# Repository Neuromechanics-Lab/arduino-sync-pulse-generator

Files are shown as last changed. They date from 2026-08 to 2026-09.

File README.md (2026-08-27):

# Arduino Sync Pulse Generator

A pseudo-random square wave generator for ATmega32U4-based Arduino boards, designed for temporal synchronization of multi-device experimental recordings.

## Purpose

When recording from multiple devices simultaneously (e.g., Vicon motion capture, EEG, eye tracking), each device has its own clock. By feeding the same pseudo-random sync signal into all devices, you can use **cross-correlation** in post-processing to precisely align all recordings temporally.

The pseudo-random pattern produces a sharp autocorrelation peak, making it far more robust for temporal alignment than a regular periodic signal.

## Hardware

Both supported boards use the ATmega32U4 at 5V/16MHz and are fully compatible.

| Board | Output pins | FQBN |
|---|---|---|
| Arduino Leonardo | 20 (0–13, A0–A5) | `arduino:avr:leonardo` |
| Pro Micro ATmega32U4 5V (e.g. Teyleten Type-C) | 18 (0–10, 14–16, A0–A3) | `arduino:avr:micro` |

- **Output voltage**: 5V HIGH / 0V LOW (hardware fixed by ATmega32U4)
- **Connection**: Wire any output pin + GND to a BNC cable for each device

If your equipment expects 3.3V logic, use a voltage divider or level shifter on the output.

> **Pro Micro note**: The standard Pro Micro footprint does not break out pins 11, 12, or 13.
> Use pins 0–10, 14–16, and A0–A3 for signal output (18 pins total).

## Setup

### Install Arduino CLI (macOS)

```bash
brew install arduino-cli
arduino-cli core update-index
arduino-cli core install arduino:avr
```

### Compile

**Arduino Leonardo:**
```bash
arduino-cli compile --fqbn arduino:avr:leonardo sync_pulse_generator
```

**Pro Micro ATmega32U4 5V:**
```bash
arduino-cli compile --fqbn arduino:avr:micro \
  --build-property "compiler.cpp.extra_flags=-DBOARD_PRO_MICRO" \
  sync_pulse_generator
```

### Upload

Both boards use the same upload command pattern. Find your port first:

```bash
arduino-cli board list
```

**Arduino Leonardo** — requires a double-tap of the reset button to enter bootloader mode:

1. Double-tap the reset button
2. Immediately run:

```bash
arduino-cli upload --fqbn arduino:avr:leonardo -p /dev/cu.usbmodemXXXX sync_pulse_generator
```

**Pro Micro ATmega32U4** — also requires a double-tap of the reset button. The port may change after the reset tap, so watch `board list` output and use the bootloader port (often a different address than the running port):

```bash
arduino-cli upload --fqbn arduino:avr:micro -p /dev/cu.usbmodemXXXX sync_pulse_generator
```

Replace `/dev/cu.usbmodemXXXX` with the port shown by `arduino-cli board list`.

## Configuration

### Compile-time defaults

Edit `sync_pulse_generator/config.h` to change default timing ranges and PRNG seed. These are loaded on first boot or after an EEPROM reset.

To target the Pro Micro pin layout, either uncomment `#define BOARD_PRO_MICRO` at the top of `config.h`, or pass `-DBOARD_PRO_MICRO` as a build flag (shown in the compile commands above).

### Runtime commands

Connect via serial monitor at **115200 baud**:

| Command | Description |
|---|---|
| `high <min> <max>` | Set HIGH duration range in ms (default: 50-500) |
| `low <min> <max>` | Set LOW duration range in ms (default: 50-500) |
| `seed <value>` | Set PRNG seed and restart pattern (default: 42) |
| `save` | Persist current settings to EEPROM |
| `reset` | Revert to config.h defaults |
| `start` | Start signal output |
| `stop` | Stop signal output (pins LOW) |
| `restart` | Re-seed PRNG and restart with same seed |
| `config` | Show current configuration |
| `help` | Show available commands |

### Persistence

Settings changed via serial commands are **not** saved automatically. Use `save` to write them to EEPROM so they survive power cycles. Use `reset` to revert to compile-time defaults.

## Reproducibility

The generator uses a deterministic xorshift32 PRNG. The same seed always produces the same sequence, so you can verify alignment across sessions or regenerate the expected pattern in analysis software.

## Alignment Utilities

Post-processing tools to align multi-device recordings using the sync channel. Located in `sync_pulse_generator/utils/` — see **[`utils/README.md`](sync_pulse_generator/utils/README.md)** for full documentation, worked examples for two and for many signals, and the complete function reference.

### Three ways to align

| Method | Use when | Files |
|---|---|---|
| **Cross-correlation** | Both copies of the signal look alike | `sync_align.*` |
| **Edge timing** | One copy went through an EMG amplifier, or you want per-transition error bars | `edge_sync.*`, `detect_edges`, `edge_delay` |
| **Timecode frames** | You need absolute time, or to know which generator run a recording belongs to | `timecode.*`, `decode_timecode`, `align_to_timecode` |

An EMG amplifier's high-pass turns each step into a transient spike, so the two waveforms stop resembling each other and correlation degrades — but their transition *times* still line up exactly, which is what edge timing measures.

### Languages

All three implement the same functions with the same names and behaviour.

| Language | Location | Dependencies |
|---|---|---|
| Python | `utils/python/` | numpy (scipy only for EMG filtering) |
| MATLAB | `utils/matlab/` | base MATLAB (Signal Processing Toolbox optional) |
| R | `utils/R/` | base R + stats (`signal` only for EMG filtering) |

### Core functions

- **`load_c3d_analog`** — Dependency-free C3D reader (no BTK or ezc3d needed), plus Nexus CSV exports. Takes rate, labels, and scaling from the file.
- **`detect_edges`** — Square-wave transitions to sub-sample precision. Two detectors: a Schmitt trigger for directly recorded signals, and signed peak detection for EMG-passed ones. Reports onset rather than peak by default, avoiding a 1–2 ms bias.
- **`edge_delay`** — Delay between two edge trains, matched by polarity and causally. Returns median, spread, per-polarity agreement, drift, and plain-language quality warnings.
- **`sync_report`** — One call for every sync channel in a recording, with a full pairwise matrix.
- **`shift_timestamps`** — Apply a measured delay to any number of channels, by relabelling time (lossless) or resampling.
- **`process_emg`** — Standard EMG chain returning every intermediate stage, with flat/railed channel detection.
- **`decode_timecode` / `align_to_timecode`** — Absolute anchors and run identity; refuses to fit across a generator restart.
- **`find_sync_lag` / `align_recordings`** — Cross-correlation alignment (offset, merge, bundle modes).

### Python CLI

```bash
# Every sync channel in a file, measured against a reference
python edge_sync.py report SquareWaveTest01.c3d

# Two named channels
python edge_sync.py delay trial.c3d --ref SquareDirect --test SquareWirelessEmg

# List what a file contains
python edge_sync.py channels trial.c3d

# Write a copy with corrected timestamps
python edge_sync.py shift trial.c3d --delay 20.6 -o corrected.csv

# Cross-correlation (the older path)
python sync_align.py lag file1.csv file2.mat --sync-col sync --fs 1000
python sync_align.py generate --seed 42 --duration 60 --fs 1000 -o expected.csv
```

Recordings in separate files, from separate devices, at different sample rates all compare directly — edge times are in seconds, so no resampling is needed.

## Author

Nathan Baune — Emory University

## License

MIT License. See [LICENSE](LICENSE).

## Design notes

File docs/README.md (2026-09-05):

# PRE-Sync documentation

| Document | Contents | Source of truth |
|---|---|---|
| [DATASHEET.md](DATASHEET.md) | Specifications, ratings, failure behaviour | hand-written |
| [INTERFACE.md](INTERFACE.md) | Pinout, signal levels, serial commands | **generated** from firmware |
| [BOM.csv](BOM.csv) | Bill of materials | hand-maintained |
| [wiring/presync-schematic.svg](wiring/presync-schematic.svg) | Electrical schematic | **generated** from `presync-schematic.yml` |
| [wiring/presync-harness.png](wiring/presync-harness.png) | Panel harness diagram | **generated** from `presync-harness.yml` |
| [TEST_PROCEDURE.md](TEST_PROCEDURE.md) | Acceptance tests for a built unit | hand-written |
| [ACCESSORIES.md](ACCESSORIES.md) | Fan-out pod, LED converter | hand-written |
| [api/](api/) | Python analysis toolkit reference | **generated** from docstrings |

## Regenerating

Three documents are generated and must not be edited by hand — an edit is
lost the next time they are rebuilt, and the source is the authority:

```sh
python3 tools/gen_interface_doc.py           # docs/INTERFACE.md
.venv-docs/bin/python tools/gen_schematic.py # docs/wiring/presync-schematic.svg
tools/gen_wiring.sh                          # docs/wiring/presync-harness.*
tools/gen_api_docs.sh                        # docs/api/
```

The last three need a virtual environment and graphviz:

```sh
brew install graphviz
python3 -m venv .venv-docs
.venv-docs/bin/pip install wireviz pdoc pyyaml numpy scipy pyxdf matplotlib
```

## Checking the BOM

```sh
python3 tools/check_bom.py
```

Reports which lines still lack a manufacturer part number, supplier or price.
The BOM is incomplete until this runs clean; **do not fill it with estimates**,
since a fabricated price is worse than a visible blank.

## What is still missing

Measurements only a built unit can provide, tracked in
[TEST_PROCEDURE.md](TEST_PROCEDURE.md): rise/fall times, channel-to-channel
skew, generator clock accuracy in ppm, and demonstration of the independent
driver claim. These appear as *TBM* in the datasheet.

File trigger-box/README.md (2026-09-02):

# PRE-Sync — trigger box for sync_pulse_generator

3D-printed, copper-foil-lined enclosure for the Pro Micro (ATmega32U4 5V)
running [`../sync_pulse_generator`](../sync_pulse_generator). Eight BNC sync
outputs; TRIG input for chaining multiple boxes off one master signal.

**Three parts, no supports anywhere:** the **frame** (walls + corner posts,
open at both ends), the **face plate** (flat display plate, screws onto one
end with countersunk M3 self-tappers into the posts), and the **lid**
(screws onto the other end). Assembled ~174 × 51 × 37 mm, 3 mm walls.

**Faces:**
- **Front:** 8 BNC outputs at 19 mm pitch, numbered `1`–`8` left to right,
  `OUTPUTS` caption above. **Each jack is driven by its own Arduino pin**
  through a 220 Ω series resistor (all pins carry the identical signal), so
  every cable has a full 5 V driver behind it — no shared drivers, no pots.
  Level control per device, if needed, is an inline attenuator pod (idea
  logged, not built).
- **Rear:** `TRIG IN` BNC + SPDT mode toggle (`FREE RUN ⟷ TRIG RUN`, arrow
  from TRIG RUN to the IN jack) under a `CONTROL` caption.
- **Left end:** `PWR` barrel jack, centered.
- **Right end:** 10-32 thread-forming ground/tether screw, dead center —
  self-taps through the wall into the copper foil inside (the shield's single
  ground point), tether ring terminal under the head outside.
- **FACE PLATE (deployed top):** Neuromechanics Lab icon
  (`logo-icon-filled.svg` — outlines filled so every shape is a solid inset) + **PRE-Sync** wordmark as a 1.2 mm **inset whose floor
  is colored** — a 0.6 mm slab of filament 1 sits directly under the recess
  inside the body, so you look into the inset and see orange at the bottom,
  body color on the walls. **10 mm blue LED centered in the neuron's soma.**
- **Lid (deployed bottom):** 4 corner screws, two keyhole mounts (M4/#8
  heads; slots toward the front — hang and slide to lock), lab attribution
  inset inside.

**All lettering is inset** (0.8 mm deboss; walls in Futura Medium 4.6 mm with light stroke fattening
so the grooves print smooth).

## Top bracing and PCB mount

The bottom edge is closed by the lid and both ends by the face and lid screws,
but the top opening had nothing holding its long edges apart — 168 mm of
unsupported wall that could bow. Two things fix that:

- **A ledge** (`ledge_w` 2.5 mm × `ledge_h` 3 mm) runs the inside of the top
  rim, turning the free edge into a flange. A flange resists bending far better
  than the same mass added as wall thickness. It stops short of the corner posts
  so the face plate still seats on the posts.
- **Two cross beams** (`beam_w` 8 mm × `beam_h` 4 mm) span the short way, wall to
  wall, at the PCB post spacing. They close the load path between the long
  walls, so the walls can no longer splay. Their top faces are **flush with the
  rim**, coplanar with the ledge and the corner posts.

**Print the frame RIM DOWN.** Flush beams are what makes that work: the whole
top surface — rim, ledge and both beams — becomes the first layer, laid flat on
the plate, and the hanging posts grow vertically off solid material. Recessed
even slightly, the beams would be 45 mm unsupported bridges whichever way up the
part printed, and the post pilots that have to hold an M2.5 thread would be
forming off a bridged surface. No supports either way up, but rim-down is the
one that prints the posts accurately.

Because the beams share the rim plane with the corner posts, the face plate now
seats on them too — more bearing surface, but the beam tops must be exactly
coplanar or the plate rocks. The model is (verified: max z equals the rim
exactly, not a layer proud).

**The board hangs from the beams**, horizontal, on four posts dropping from
their undersides (`pcb_hang` 4 mm, M2.5 self-tappers into `pcb_pilot` 2.2 mm).
This replaces the earlier scheme, where four posts stood off the rear wall and
the board mounted vertically on their ends.

Two things that buys:

- **Serviceable from both faces.** Take the logo face off (top) to reach the
  beams and the component side; take the lid off (bottom) to reach the solder
  side.
- **Out of the way of everything.** The board is centred at `pcb_cx` 34 /
  `pcb_cy` −11, so it spans x −4..72 and y −21..−1 — pulled back against the
  rear wall, leaving 23.5 mm clear in front for the eight BNC bulkhead bodies,
  and well clear in x of the face LED at x −51. It lands at z 23, 6 mm above the
  z 17 centreline of the BNC and barrel jacks.

> **`pcb_dx` (76) and `pcb_dy` (15) are still unverified.** `dx` carried over
> from the vertical scheme; `dy` is a guess at the hole spacing across the
> board's 20 mm dimension. Measure the real board before printing — four posts
> at the wrong pitch line up with nothing. Check them on `trigger-hole_test`
> along with the connector diameters.

## Printing

STLs only — slice in Bambu Studio yourself (never a command-line slice; the
CLI can't resolve Bambu's filament profiles and produces 0 g / no-extrusion
files). `./export-parts.sh` regenerates `exports/stl/*.stl` after any change.
Every part prints flat exactly as exported — **no rotation, no supports.**

1. `trigger-hole_test` first (~10 min): every hole + keyhole + an inset label
   sample. VERIFY bnc/switch/barrel/led diameters against the real parts.
2. `trigger-frame` — walls only, either end down. Single color.
3. **Face plate, two-color:** import `trigger-face.stl` AND
   `trigger-face_art.stl` together → **Yes** to "load as a single object with
   multiple parts" → `trigger-face_art` (the recess-floor slab) → filament 1
   (orange), `trigger-face` → filament 2. Face up as exported. The color
   change is 3 layers just below the top surface. Check the sliced weight is
   a real number before printing.
4. `trigger-lid` flat as-is, single color.

Assembly: 4 × M3 self-tappers through the face plate's countersinks into the
posts (either in-plane rotation of the plate works — pick the one where the
wordmark reads the way you want relative to the OUTPUTS wall), 4 more
through the lid. LED holder nut goes on inside the plate before it's screwed
down.

## Copper foil shielding

Line the interior with conductive-adhesive copper tape: overlap seams,
ground the foil to circuit GND at exactly ONE point (the ground screw), keep
it clear of the Pro Micro's underside. BNC shells touching the foil is fine
(shield = GND).

## Electrical notes

- Outputs: 8 pins (Pro Micro: 4, 5, 6, 7, 8, 9, 10, 14) → 220 Ω → BNC
  center; all BNC shells to GND. Pins 2/3 are reserved by the firmware for
  TRIG IN / mode switch.
- SPDT toggle: MTS-102 style (6 mm bushing, 6.5 mm hole, fit-tested).
- TRIG IN → 1 kΩ series → pin 2; switch common → pin 3, FREE throw → GND.
  See the sync_pulse_generator README for the arming logic.

## Accessory pucks (`pods.scad`)

Round Ø60 pucks on a shared body, all parts flat, no supports. Each puck =
`base` (keyhole plate, common) + a ring + a top plate, 4 × M3 self-tappers
each end into the ring's posts. Hung by the keyhole, the top plate faces out
and the jacks run left–right. Exported as `exports/stl/pod-*.stl`.

| Puck | Ring | Top | Inside |
|---|---|---|---|
| **GAIN** (inline attenuator) | `pod-ring` — IN + OUT, 40 tall | `pod-top_gain` — pot, `GAIN`, arc arrow `LOW` → `HIGH` | IN center → pot end, wiper → OUT center, other end → shields. High-impedance loads only |
| **LED** | `pod-ring_in` — IN only, 28 tall | `pod-top_led` — Ø20 boss with a **1/4"-20 heat-set insert** for a hollow **gooseneck** (mic/lamp type: wires run inside, holds any position, never free-spins) | IN center → series resistor (~220 Ω for a 10 mm LED at 5 V) → up the gooseneck |
| | | `pod-led_head` — screws onto the gooseneck's far end: insert in the bottom, 10 mm LED press-fit + 14 mm ring seat on top, wires through the middle | |
| **SOUND** | `pod-ring_in` | `pod-top_sound` — pocket for a 23 mm **5 V active piezo buzzer**, grille, `VOL` pot, `LEVEL`/`EDGE` toggle | see below |

**SOUND puck circuit** — buzzer + ← VOL pot (series, volume) ← IN center.
The SPDT toggle sits on the buzzer's − side and picks how it reaches the
shield (ground):

- `LEVEL`: buzzer − → shield directly. Sounds for the whole HIGH.
- `EDGE`: buzzer − → NPN collector (2N3904 / BC547), emitter → shield. Base
  ← 22 kΩ ← 1 µF ← IN center, with 10 kΩ base→shield and a 1N4148 from
  shield to base (cathode at base) to clamp the falling-edge spike. The
  capacitor passes only the rising edge, so the transistor conducts for
  ≈ RC ≈ 20 ms: one blip per rising edge, powered by the line itself (every
  HIGH lasts ≥ 50 ms). Change 1 µF / 22 kΩ for a longer or shorter blip.

Parts to buy: 1/4"-20 heat-set brass inserts (two per LED puck — VERIFY the
OD against `gn_insert_d`), a 1/4"-20 gooseneck (6–12"), a 5 V active piezo
buzzer (VERIFY `buzzer_d`). Print `pod-top_led` boss-up and `pod-top_sound`
as exported (outside face on the bed, pocket walls growing up).

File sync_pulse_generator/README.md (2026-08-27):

# Sync Pulse Generator

Pseudo-random square-wave sync pulse generator on an ATmega32U4 (Pro Micro /
Leonardo), for cross-correlation-based temporal alignment of multi-device
recordings (Vicon, EEG, DAQ, audio, video). Hardware enclosure: the
**PRE-Sync** box (`../trigger-box/`) — 2 gain-controlled banks of 3 BNC
outputs, TRIG input + FREE/TRIG run switch.

All output pins carry the same 5 V / 0 V signal. HIGH and LOW durations are
drawn pseudo-randomly (xorshift32, fixed seed) from configurable ranges —
the same seed always produces the same sequence, so the expected waveform
can be recreated offline and any recording aligned to it by
cross-correlation (`utils/R/sync_align.R`).

## Timecode frames (hybrid mode, default ON)

Every 10 s (configurable) the pseudo-random train is interrupted by one
**timecode frame** encoding elapsed seconds since the PRNG started —
constant 5 V amplitude, information purely in pulse timing. **Frames start
exactly on the tick:** the random segment that would cross the tick is cut
short 20 ms early, the output holds LOW for that lead-in, and the first
preamble pulse rises ON the tick — so a decoded frame's first edge marks
precisely `elapsed` seconds of generator time (ms-accurate anchors, not
"somewhere in that second").

```
preamble                 payload: 52 bits as gaps between 5 ms pulses
P──10──P──10──P ── g₀ ──P── g₁ ──P── ... ──g₅₁──P
                  15 ms = 0   25 ms = 1
bits, MSB first:  [16-bit run ID][32-bit elapsed seconds][4-bit checksum]
checksum: XOR of all 4-bit nibbles of run ID and elapsed seconds
```

**Run ID** is a persistent EEPROM counter that increments on every PRNG
(re)start — power-up, `start`, `restart`, `seed`, `reset`. Since the fixed
seed makes every run's waveform identical, the run ID is what tells run 731's
`t=50 s` apart from run 732's: **(run ID, elapsed) uniquely identifies every
moment the box has ever emitted.** A recording found years later self-reports
which session it belongs to. (Counter wraps at 65535; it is stored outside
the config block, so `save`/`reset` never touch it.)

Why: with a fixed seed the PR train itself already encodes absolute position
(any chunk cross-correlates to one offset in the reconstructed template) —
frames add three practical things on top: **no-compute anchors** (decoding
one frame beats correlating against an hours-long template), **drift-immune
point anchors** (each frame decodes independently of accumulated sample-rate
error), and **run identity** (see Run ID above — the one thing the PR train
cannot provide, since every run's waveform is identical). Frames are deterministic and consume
no PRNG draws, so the complete hybrid signal is still exactly reproducible
from (seed, config): cross-correlation works across frames like any other
signal — they're simply part of the fingerprint (and each frame differs, so
no periodicity artifact).

Design rules baked in:
- PR durations (default min 50 ms) can never imitate frame timing
  (5–25 ms) — preambles are unambiguous. The cut-short segment before a
  frame can be arbitrarily brief, which is why the lead-in is 20 ms: a
  short HIGH stub then the lead-in gives a 25 ms edge interval — neither a
  preamble (15) nor a bit (20/30).
- The PRNG draw for the cut-short segment still happens, so the template
  generator reproduces the clamp exactly from (seed, config).
- **Edge-polarity friendly:** frame pulses have constant width, so a
  falling-edge-only recording decodes identically; its anchors are exactly
  `TC_PULSE_MS` (5 ms) late, corrected by `edge="falling"` in the decoders.
  In an unlabeled edge stream, the frame's 5 ms intervals even identify
  which edges are rises.
- Cameras/LED pods can't resolve frame gaps — they don't need to: they
  align by cross-correlation against the recreated template as always.

## FREE RUN / TRIG RUN (the rear-panel switch)

The PRE-Sync box's SPDT toggle selects the run mode (read live — flipping
it mid-session acts immediately):

- **FREE RUN** — output starts at power-up, exactly as before.
- **TRIG RUN** — outputs hold LOW until a rising edge arrives on the
  **TRIG IN** BNC, then a fresh run starts (new run ID, elapsed = 0).
  Chain several boxes from one master pulse and they start in sync; each
  box still stamps its own run ID. Once running, further TRIG edges are
  ignored — re-arm by flipping the switch or power-cycling.

Wiring (see `config.h`): switch common → pin 3, FREE-throw → GND;
TRIG BNC center → ~1 kΩ series resistor → pin 2. The TRIG input must sit
LOW ≥ 20 ms before an edge counts, so an unconnected jack can never
false-trigger (an idle master holding 0 V arms it). Pins 2 and 3 are
excluded from the output set; all other pins still carry the signal.

## Serial commands (115200 baud)

```
high <min> <max>   low <min> <max>    seed <value>
tc on|off          tcint <seconds>    save
start | stop | restart | reset | config | help
```

`tc on` / `tcint` take effect immediately, on the run's interval grid
(never a burst of overdue frames); `tcint` minimum is 2 s (a frame is
~1.65 s). `save` persists everything (including timecode settings) to
EEPROM.
EEPROM magic is 0xA8 — older saved configs (0xA7) are invalidated and
defaults reload on first boot after this firmware update.

## Concept figure

`docs/timecode_figure.{svg,png}` — the hybrid signal at three zoom levels
(12 s overview → one frame with its fields bracketed → preamble and first
bits at ms scale), generated bit-exact from the reference implementation by
`utils/python/timecode_figure.py`. `timecode_figure_bare.*` is the same
waveform with no labels, for annotating from scratch. SVG stays editable.

## Offline tools (`utils/`)

Full documentation, worked examples for two and for many signals, and the
function reference across all three languages: **[`utils/README.md`](utils/README.md)**.

Three ways to align, for different situations:

- **Edge timing** (`edge_sync.py`, `detect_edges`/`edge_delay` in all three
  languages) — measures the delay transition by transition, with error bars.
  The right tool when one copy of the square wave has been through an EMG
  amplifier: the high-pass turns each step into a spike, so the waveforms no
  longer resemble each other but their edge *times* still line up.
- **Timecode frames** (`timecode.py`, `decode_timecode`, `align_to_timecode`)
  — absolute anchors and run identity. `generate_template()` recreates the
  exact hybrid edge sequence from (seed, config); `decode_frames()` extracts
  anchors from recorded edge times; `align_to_timecode()` maps a recording
  onto the generator's timeline and refuses to fit across a run boundary.
  Run `python timecode.py` for a round-trip self-test.
- **Cross-correlation** (`sync_align.*`) — whole-waveform alignment when both
  copies look alike.

Also here: a dependency-free C3D/CSV reader, a standard EMG processing chain
with quality checks (flat and railed channels are flagged, not silently
processed), and a four-panel visual QC figure.

## Build

```
arduino-cli compile --fqbn arduino:avr:leonardo .
arduino-cli compile --fqbn arduino:avr:micro \
  --build-property "compiler.cpp.extra_flags=-DBOARD_PRO_MICRO" .
```

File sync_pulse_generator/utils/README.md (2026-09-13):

# Alignment utilities

Offline tools for aligning multi-device recordings that share the sync
generator's square wave.

**Python is the reference implementation.** The alignment core — template
generation, edge detection, edge delay, timecode decoding and the N-recording
lock — exists in **MATLAB, Python and R** with matching function names and
behaviour, so pick whichever your analysis already lives in for that work.

Several capabilities are **Python-only**, and the table at the end of this
file marks them: the offset/drift/jitter/loss decomposition (`truth.py`), the
one-call analysis and report (`analyze.py`), template-free pairwise diagnosis
(`diagnose.py`), the **event-channel decoder** (`events.py`), and XDF/LSL
loading. If your work needs those, use Python.

---

## Which tool for which problem

There are two independent ways to align recordings, and they answer different
questions.

| | **Cross-correlation** | **Edge timing** | **Timecode frames** |
|---|---|---|---|
| Files | `sync_align.*` | `edge_sync.*`, `detect_edges`, `edge_delay` | `timecode.*`, `decode_timecode` |
| Gives you | Relative offset between two recordings | Relative offset, per-transition, with error bars | Absolute position on the generator's own timeline |
| Needs | Both signals to look alike | Clean detectable edges | Timecode enabled in firmware |
| Works when one signal went through an EMG amp | Poorly | **Yes** | Yes |
| Tells you *which run* you recorded | No | No | **Yes** |

**Rule of thumb.** If one copy of your square wave has been through an EMG
amplifier, use **edge timing** — the amplifier's high-pass turns each step
into a spike, so the two waveforms no longer resemble each other and
correlation degrades, but their transition *times* still line up exactly. If
you have clean matching waveforms, cross-correlation is fine and needs no
edge detection. If you need to know *when in absolute terms* a recording
happened, or which generator run it belongs to, decode the **timecode
frames**.

These compose: use frames for coarse absolute anchors, edges or correlation
to refine between them.

---

## Quick start: delay between two channels

The common case — one recording, two channels carrying the same square wave,
one of them fed through an EMG sensor.

**MATLAB**

```matlab
rec = load_c3d_analog('SquareWaveTest01.c3d');   % or a Nexus CSV export
report = sync_report(rec);                       % auto-detects sync channels
```

```
Reference: Voltage.2-SquareDirect

Channel                       delay(ms)       sd      IQR      n
Voltage.16-SquareWirelessEmg     20.608    0.377    0.446    197
```

**Python**

```bash
python edge_sync.py report SquareWaveTest01.c3d
```

```python
from edge_sync import load_c3d_analog, sync_report
rec = load_c3d_analog('SquareWaveTest01.c3d')
rep = sync_report(rec)
print(rep.delays_ms)          # one delay per non-reference sync channel
```

**R**

```r
source('edge_sync.R')
ref  <- detect_edges(direct_channel,   fs)
test <- detect_edges(wireless_channel, fs)
r <- edge_delay(ref, test)
cat(sprintf('%.3f ms\n', r$delay_ms))
```

`sync_report` finds the sync channels itself by looking for labels containing
`square`, `sync`, or `trig` **and** confirming the channel actually contains
transitions — so a promisingly-named but unplugged channel will not derail
the comparison. Name them explicitly when the auto-detection is not what you
want:

```matlab
report = sync_report(rec, 'channels', {'SquareDirect', 'SquareWirelessEmg'}, ...
                          'reference', 'SquareDirect');
```

---

## Three or more signals

`sync_report` handles any number of sync channels in one recording. Every
non-reference channel is measured against the reference, so N channels give
N−1 delays on a common baseline, plus a full pairwise matrix.

```matlab
report = sync_report(rec);
report.delays_ms        % delay of each channel vs the reference
report.pairwise_ms      % full N x N matrix of every pair
report.pairwise_labels  % row/column names for that matrix
```

The pairwise matrix is antisymmetric: `pairwise_ms(a,b) == -pairwise_ms(b,a)`.
Use it to sanity-check consistency — if A→B is 20 ms and B→C is 5 ms, then
A→C should be 25 ms. A mismatch means one channel's edges are being
mis-detected.

### Separate files, separate devices

When your signals live in **different files** — Vicon in a C3D, EEG in its own
format, a DAQ in a CSV — load each one, detect edges on its sync channel, and
compare the edge trains directly. Nothing requires the recordings to share a
file, a sample rate, or a start time.

**MATLAB**

```matlab
vicon = load_c3d_analog('trial.c3d');
eeg   = load_c3d_analog('eeg_export.csv');   % any CSV with a rate or time column

e_vicon = detect_edges(vicon.data(:, find_channel(vicon, 'SquareDirect', 'unique', true)), vicon.fs);
e_eeg   = detect_edges(eeg.data(:,   find_channel(eeg,   'Sync',         'unique', true)), eeg.fs);

d = edge_delay(e_vicon, e_eeg);
fprintf('EEG lags Vicon by %.3f ms (sd %.3f, n=%d)\n', ...
        d.delay_ms, d.delay_std_ms, d.n_matched);
```

**Python**

```python
vicon = load_c3d_analog('trial.c3d')
eeg   = load_c3d_analog('eeg_export.csv')

e_vicon = detect_edges(vicon.channel('SquareDirect'), vicon.fs)
e_eeg   = detect_edges(eeg.channel('Sync'),           eeg.fs)

d = edge_delay(e_vicon, e_eeg)
print(d)          # prints delay, spread, match rate, drift, warnings
```

Sample rates may differ — edge times are in seconds, so a 1000 Hz recording
and a 2048 Hz one compare directly with no resampling.

### Chaining several devices to one reference

Pick one device as the master and measure everything against it, so all
offsets share a baseline:

```python
devices = {
    'vicon': load_c3d_analog('trial.c3d'),
    'eeg':   load_c3d_analog('eeg.csv'),
    'daq':   load_c3d_analog('daq.csv'),
}
sync_col = {'vicon': 'SquareDirect', 'eeg': 'Sync', 'daq': 'ch0'}

edges = {k: detect_edges(v.channel(sync_col[k]), v.fs) for k, v in devices.items()}

ref = 'vicon'
for name, e in edges.items():
    if name == ref:
        continue
    d = edge_delay(edges[ref], e)
    print(f'{name:8s} lags {ref} by {d.delay_ms:8.3f} ms  '
          f'(sd {d.delay_std_ms:.3f}, {d.n_matched}/{d.n_reference} edges)')
```

If a device's clock could be *ahead* of the reference, widen the causal
window — by default matching assumes the test signal cannot precede the
reference:

```python
d = edge_delay(edges[ref], e, min_delay=-50, max_delay=50)
```

---

## Applying the correction

Once you have a delay, shift the late recording's timestamps to match:

```matlab
corrected = shift_timestamps(rec, d.delay_ms);              % all channels
corrected = shift_timestamps(rec, d, 'channels', emg_idx);  % a subset
```

```python
t, data, info = shift_timestamps(rec, d)          # or a plain number of ms
t, data, info = shift_timestamps(rec, 20.6, resample=True)
```

**Sign convention.** A positive delay means the test recording arrived *late*,
so its timestamps move *earlier*. Pass `invert` if your delay was measured the
other way round.

**Two correction styles.** The default rewrites the time vector and leaves the
samples untouched — nothing is interpolated, so no data is altered, and the
recording simply starts at a non-zero time. `resample` instead keeps the
original time base and moves the *data* onto it by interpolation; use it only
when something downstream insists every recording share one grid, since
interpolation is lossy.

From the CLI:

```bash
python edge_sync.py shift trial.c3d --delay 20.6 -o corrected.csv
python edge_sync.py shift trial.c3d -o corrected.csv     # measures it first
```

---

## Peak vs onset: a bias worth knowing about

When the square wave has passed through an EMG amplifier, each step becomes a
transient spike. Where on that spike you measure changes the answer, and
**both choices are biased late** — what separates them is whether the bias
stays constant.

| estimator | bias | varies with amplifier? |
|---|---|---|
| `locate='onset'`, fraction 0.25 (default) | +0.45 ms | no |
| `locate='onset'`, fraction 0.80 | +1.00 ms | no |
| `locate='peak'` | +1.3 to +1.7 ms | **yes** |

Measured against synthetic signals of known delay at 1000 Hz, across
amplifier time constants from 1 to 20 ms. The peak's bias grew with the time
constant; the onset's did not move at all.

That constancy is the point. A bias that is the same for every edge cancels
out when you compare two channels recorded through the same hardware, so the
*difference* you care about survives. A bias that tracks the amplifier does
not cancel, and you cannot correct for it without knowing the amplifier's
response. Onset is therefore the default.

```matlab
e = detect_edges(x, fs);                                   % onset, 0.25
e = detect_edges(x, fs, 'onset_fraction', 0.8);            % less bias-free, tighter
e = detect_edges(x, fs, 'locate', 'peak');                 % most reproducible
```

**The trade-off is noise.** Low on the flank the signal is still small, so on
real recordings the onset spread is wider than the peak's. On the reference
60 s recording:

| | median | IQR | matched |
|---|---|---|---|
| onset 0.25 | 21.31 ms | 0.80 ms | 213/213 |
| onset 0.80 | 22.21 ms | 0.31 ms | 213/213 |
| peak | 22.92 ms | 0.36 ms | 213/213 |

Raising the fraction buys precision back at the cost of a larger (still
constant) bias. Report which setting you used — the numbers are not
interchangeable.

**On this recording the onset delays are bimodal**, splitting into clusters
about 0.9 ms apart (visible in panel 3 of `plot_sync_check`). Both clusters
contain rising and falling edges at equal spike amplitude, so it is not a
polarity bug or weak-spike effect — it is where the flank crossing lands
relative to the 1 ms sample grid. The median is unaffected, and raising
`onset_fraction` onto the steeper part of the flank collapses it. Look at the
histogram before quoting a mean.

## How edge matching works

`edge_delay` pairs edges under three rules, each preventing a specific failure:

1. **Polarity is respected.** A rising edge is only matched to a rising edge.
   Mixing them inflates the spread, because a rise and a fall are different
   events separated by a pulse width. (Detecting on the *signed* signal rather
   than a rectified copy is what makes this possible — rectifying discards
   the sign.)
2. **Matching is causal.** A candidate must fall inside
   `[min_delay, max_delay]`. The test signal cannot physically precede the
   reference, so a negative-delay pairing is a detection artefact and is
   excluded rather than averaged in.
3. **Ties go to the largest peak.** Spurious peaks are small; the real
   transition is not.

On real data these three together took a measurement from *9 impossible
negative-delay outliers, sd 6.3 ms* down to *zero outliers, sd 0.27 ms*.

**Check `result.warnings` before trusting a number.** It flags low match
rates, outliers, excessive spread, rising/falling asymmetry (which usually
means one polarity is being mis-located), and drift. The rising-vs-falling
agreement is the single best check that pairing is correct — on a good
measurement the two agree to well under 0.1 ms.

---

## Timecode frames: absolute time and run identity

When the firmware has timecode enabled, every 10 s the train carries a frame
encoding **run ID** and **elapsed seconds**. Decoding one frame places the
recording on the generator's timeline without any correlation.

```matlab
e = detect_edges(rec.data(:, ch), rec.fs);
f = decode_timecode(e.time(e.polarity > 0));    % or 'edge','falling'
a = align_to_timecode(f);

fprintf('run %d; recording t=0 is generator t=%.3f s\n', ...
        a.primary.run_id, a.to_generator(0));
```

```python
frames = decode_frames(rising_edge_times)
a = align_to_timecode(frames)
a['to_generator'](0.0)      # recording time -> generator time
a['to_recording'](50.0)     # generator time -> recording time
```

### Runs, FREE vs TRIG, and why run ID matters

The generator's elapsed clock is **not a wall clock**. It counts from the
start of the current *run*, and every run start increments a persistent run
ID. A run starts when:

- the box boots in **FREE RUN** (output begins immediately, elapsed 0 =
  power-up);
- a trigger edge arrives on TRIG IN in **TRIG RUN** (outputs are held LOW
  until then, so **elapsed 0 is the trigger** — this is what lets several
  devices start together from one master pulse);
- the mode switch is moved to FREE RUN;
- a serial `start` or `restart` is issued.

Because the run ID changes at every one of those events, **two recordings
share a timeline only if their run IDs match.** Elapsed values from different
runs count from different zeros and cannot be compared. `align_to_timecode`
treats a run ID change as a hard boundary, reports each run separately, and
warns rather than silently fitting across it:

```python
a = align_to_timecode(frames)
if a['n_runs'] > 1:
    print(a['warnings'][0])       # explains the restart
    for run_id, frs in split_runs(frames):
        ...                       # handle each segment separately

a = align_to_timecode(frames, expect_run=138)   # or just pick one
```

Flipping the switch from FREE to TRIG mid-session stops output and waits;
flipping back, or triggering, begins a *new* run with a *new* ID. That
signature is embedded in every frame, so a recording self-reports which start
it belongs to.

### Anchor accuracy (frames start on the tick)

A frame starts **exactly** on its interval tick: the firmware cuts the random
segment that would cross the tick short, holds LOW for a 20 ms lead-in, and
the first preamble pulse rises on the tick. So `t_rec` of a decoded frame
*is* `elapsed_s` of generator time, to the millisecond — every anchor is
exact, and the offsets `elapsed - t_rec` agree across frames to within the
recorder's own edge-timing resolution.

What `align_to_timecode` does with that:

- The offset is the **mean** of all anchors (every frame carries equal
  weight).
- **Drift** is a least-squares slope through all anchors, reported only when
  it exceeds the 10 ms anchor tolerance over the span observed *and* clears
  the slope's own noise floor by 3×; otherwise `drift_ppm` is `0` with
  `drift_resolvable = false`. Verified: a 200 ppm recorder clock is
  recovered to within 0.05 ppm from a 95 s record.
- Residuals above 10 ms about the fit produce a warning: frames can't be
  late any more, so scatter means a mis-decoded frame or a recorder whose
  edge timing is coarser than expected.

`max_pulse_ms` is still accepted by all three implementations for backward
compatibility but is ignored — it parameterised the emission jitter of
firmware that emitted frames late.

---

## EMG processing

`process_emg` runs the conventional chain and returns **every intermediate
stage**, so any step can be plotted to see where a signal goes wrong:

```
raw -> detrend -> bandpass -> (notch) -> rectify -> envelope
```

```matlab
p = process_emg(rec.data(:, ch), rec.fs);          % defaults: 20-450 Hz, 4 Hz envelope
p = process_emg(x, fs, 'band', [20 450], 'notch', 60, 'mvc', mvc_value);
plot(p.time, p.raw); hold on; plot(p.time, p.envelope);
```

The bandpass is zero-phase (applied forwards and backwards), so it adds no
lag — which matters here, since a lag would corrupt the very timing these
tools measure.

Check `p.warnings`, which flags in plain language:

- **flat** channels — nothing connected, or the sensor is off;
- **railed** channels — a disconnected sensor floats to the supply limits and
  looks like a large signal unless you check. (This is not hypothetical: in
  the reference recording an unplugged channel sat at ±1.25 V with a standard
  deviation larger than every real EMG channel.)
- low signal-to-noise, and strong mains contamination.

---

## Visual check

```matlab
plot_sync_check(rec);                      % auto-detects everything
plot_sync_check(rec, report, 'emg', {'Sol','TA'}, 'window', [0 5]);
```

Four panels: both square-wave channels with detected edges marked, per-edge
delay against trial time, the delay histogram, and raw+envelope per EMG
channel. Look at this before trusting any number — a flat band in panel 2
means a fixed latency, a slope means clock drift, and scatter means detection
trouble.

---

## File formats

`load_c3d_analog` reads:

- **C3D** — a dependency-free reader (no BTK, no ezc3d). Handles
  Intel/DEC/MIPS byte orders and both float and scaled-integer storage, and
  takes the sample rate, labels, and scaling from the file rather than
  assuming them.
- **CSV / TXT** — Nexus ASCII exports (the `Devices` section with its rate
  header), or any plain CSV with a `time` column.

To get a C3D out of Vicon Nexus: open the trial, then **File → Save Trial**.
If Save is greyed out, add an **Export C3D** operation in the Pipeline pane
and run it. `.x1d` / `.x2d` files are raw camera data and contain no analog
channels.

Channel labels keep their Vicon prefixes (`Voltage.2-SquareDirect`);
`find_channel` matches on any substring, so you can ask for `SquareDirect`
without spelling the rest.

---

## Aligning several recordings at once

`align.py` / `align_sources.m` / `align.R` handle the messy case: several
devices, each with its own clock, start time, sample rate, and way of
reporting the sync signal — one a continuous waveform, another only rising
edges, a third only falling edges — some dropping frames, none agreeing on
when zero was.

The trick is not to align recordings to each other. The generator's output is
fully determined by (seed, config), so the intended waveform is regenerated
from code and every recording is locked **independently** to that template.
Alignment is then transitive: no reference device, no pairwise matrix, no
accumulated error, and recordings that never overlap in wall-clock time still
land on one timeline.

```python
from align import Source, align_recordings

srcs = [
    Source.from_continuous('vicon', vicon_sync, fs=1000, data=vicon_data),
    Source.from_edges('eeg', rising_times, polarity='rising'),
    Source.from_continuous('daq', daq_sync, fs=2048),
]
res = align_recordings(srcs, mode='lags')          # just the numbers
res = align_recordings(srcs, mode='global_time')   # per-recording timeline
res = align_recordings(srcs, mode='stitch')        # one merged table
```

```matlab
srcs = [source_from_continuous('vicon', sync, 1000), ...
        source_from_edges('eeg', rising_times, 'rising')];
r = align_sources(srcs, 'mode', 'lags');
```

```r
srcs <- list(source_from_continuous("vicon", sync, 1000),
             source_from_edges("eeg", rising_times, "rising"))
r <- align_recordings_tc(srcs, mode = "lags")
```

**How it locks.** A decoded timecode frame beats everything: it states its
elapsed second outright, checksum-verified, and is the only evidence of
*which run* was recorded. Failing that, the pseudo-random interval gaps are
fingerprinted — which still works for a device that low-passes the signal
past frame decoding but keeps clean 50–500 ms edges.

**What it handles**, each verified against ground truth in all three
languages:

| | result |
|---|---|
| Different sample rates | 500/1000/2048 Hz mixed, lag exact to the ms |
| Rising-edge-only / falling-edge-only | offset to <0.01 s, 100% matched |
| Clock drift | 300 ppm recovered as +301 to +307 ppm |
| Missing block (honest timestamps) | reported as a hole, **no** false drop |
| Lost-count step | split into segments, step within 2 ms of truth |
| Different generator runs | refused, not silently merged |

**Two failure modes, deliberately distinguished.** A *hole* — samples missing
but timestamps honest — needs no correction. A *lost-count step* — the
recorder's counter falls behind, so later samples are labelled early — splits
the time map. Conflating them either invents corrections or misses real ones.

**Drop localization is coarse**: a step is bracketed to one anchor window
(one timecode interval, 10 s by default), not pinpointed. Good for flagging
and cutting, not for sample-level repair.

## Function reference

| Purpose | MATLAB | Python | R |
|---|---|---|---|
| Load analog data | `load_c3d_analog` | `load_c3d_analog` | — |
| Find a channel | `find_channel` | `rec.find` / `rec.channel` | — |
| Detect edges | `detect_edges` | `detect_edges` | `detect_edges` |
| Delay between two | `edge_delay` | `edge_delay` | `edge_delay` |
| All sync channels | `sync_report` | `sync_report` | — |
| Apply a delay | `shift_timestamps` | `shift_timestamps` | `shift_timestamps` |
| EMG chain | `process_emg` | `process_emg` | `process_emg` |
| Visual check | `plot_sync_check` | — | — |
| Decode frames | `decode_timecode` | `decode_frames` | `decode_timecode` |
| Absolute alignment | `align_to_timecode` | `align_to_timecode` | `align_to_timecode` |
| Split at run change | — | `split_runs` | `split_runs` |
| Recreate the signal | `generate_sync_signal_tc` | `generate_template` | `generate_sync_signal_tc` |
| **Align N recordings** (entry point) | `align_sources` | `align_recordings` | `align_recordings_tc` |
| Build one source | `source_from_*` | `Source.from_*` | `source_from_*` |
| Lock one recording | `align_lock` | `lock_source` | `align_lock` |
| Cross-correlation | `find_sync_lag` | `find_sync_lag` | `find_sync_lag` |

### Python-only

These are whole capabilities, not wrappers. There is no MATLAB or R
equivalent to call.

| Purpose | MATLAB | Python | R |
|---|---|---|---|
| Offset/drift/jitter/loss decomposition | — | `truth.score` / `truth.classify` | — |
| Corrected timestamps from a report | — | `truth.correct` | — |
| One call, full analysis + report | — | `analyze_file` / `analyze_streams` | — |
| Template-free pairwise diagnosis | — | `diagnose_pair` | — |
| Signal fidelity against the grid | — | `check_fidelity` | — |
| **Decode the event channel** | — | `decode_events` | — |
| Load XDF / LSL recordings | — | `load_xdf` | — |

A `—` in either table means the capability is genuinely absent in that
language, not merely unwrapped. `plot_sync_check` is MATLAB-only for the same
reason, and `split_runs` exists only in Python and R.

## Dependencies

- **MATLAB** — base MATLAB. `filtfilt`/`movmean` are used when present and
  hand-rolled otherwise, so the Signal Processing Toolbox is optional.
- **Python** — `numpy`. `scipy` only for EMG filtering.
- **R** — base R + `stats`. The `signal` package only for EMG filtering;
  `process_emg` reports what it had to skip rather than failing.

## Self-tests

```bash
python test_edge_sync.py  # 7 regression tests over the edge/EMG path
python timecode.py        # round-trip: generate -> decode -> verify, plus run boundaries
```

`test_edge_sync.py` covers the failure modes found while building this, so a
regression surfaces as a failed assertion rather than a plausible-looking
wrong number: channel-name prefix collisions, causal matching, polarity
pairing, the onset's bias staying independent of the amplifier while the
peak's does not, railed-channel detection, and the cross-detector edge-count
warning.

## Verification status

All three implementations were run against the same reference recording
(60 s, 1000 Hz, 28 channels) and agree to three decimal places:

| | delay | IQR | matched |
|---|---|---|---|
| MATLAB R2024b | 21.312 ms | 0.803 | 213/213 |
| Python | 21.312 ms | 0.803 | 213/213 |
| R | — (validated on synthetic ground truth) | | |

Against synthetic signals of known delay, all three recover it with the same
bias to the millisecond across amplifier time constants from 1 to 20 ms.

One practical note on MATLAB: `plot_sync_check` returns in about 17 seconds,
but rendering the figure to a file with `exportgraphics` takes several minutes
in a headless `-batch` session because the figure is eleven panels tall.
Interactively it simply appears. If you need it scripted, export fewer EMG
channels via the `'emg'` option or pass `'max_emg'`.

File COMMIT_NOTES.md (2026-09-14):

- fix(analysis): the duration quantum is now resolved from the recording rather than assumed. Decoders had defaulted to 0.25 ms, which is correct for firmware that emits timecode frames but wrong for every recording made before them — those failed to lock with "no part of this recording matches 6 h of the generator's output", which reads as bad data when it is a configuration mismatch. score() now asks the recording to declare itself: a decodable timecode frame means the full variant and the current quantum; no frame means the simple variant, which predates the finer quantum and is always 5 ms. An explicit step_ms= still wins. The resolved value and the reason are carried on the report (2026-09-13T18:30:00-04:00)
- fix(analysis): classify() rebuilt the template and derived the gross-vs-jitter threshold from the caller's step_ms argument rather than the value score() had actually locked on. With no argument passed that silently used a different quantum than the lock, so the template no longer matched the waveform and the gross cut was scaled wrong. Both now read the resolved value off the report (2026-09-13T18:30:00-04:00)
- fix(analysis): timecode frames were never decoded from a both-edges stream. decode_frames needs a single polarity — an interleaved list halves every interval and matches no preamble — but analyze_streams passed the stream through unchanged, behind a conditional whose two branches were identical and a bare except that discarded the failure. It now tries each polarity and keeps whichever yields more valid frames, as the align path already did, and a decode error is reported instead of swallowed (2026-09-13T18:30:00-04:00)
- feat(analysis): every report states which quantum it used and how that was determined, before any number. Getting the quantum wrong does not degrade a result, it prevents a lock, so the assumption is visible on every run rather than only when something fails. A frameless recording additionally prints how to override. A failed lock now names the quantum tried, the reason it was chosen, and the alternative to retry with (2026-09-13T18:30:00-04:00)
- fix(report): the on-tick line hardcoded "the correct 5 ms tick" regardless of the quantum in use. It now renders the resolved value (2026-09-13T18:30:00-04:00)
- fix(docs): the utils README claimed everything exists in MATLAB, Python and R with matching behaviour, and described the gaps as missing convenience wrappers. Several are whole capabilities with no equivalent to call: the offset/drift/jitter/loss decomposition, the one-call analysis and report, template-free pairwise diagnosis, signal fidelity checking, XDF/LSL loading, and the event-channel decoder — which the function table did not list at all, so a reader choosing a language could not see what they would give up. Added a Python-only table and stated plainly that a dash means absent, not unwrapped (2026-09-13T18:30:00-04:00)
- fix(tests): the synthetic fixtures built their edge trains at the library default quantum and then relied on the decoder defaulting to the same value. With the quantum now resolved from the signal, a frameless synthetic stream is read as the simple variant, so the fixtures declare their own quantum explicitly. This is the honest form: a generated stream carries no protocol and cannot be asked (2026-09-13T18:30:00-04:00)
- test(analysis): round-trip accuracy harness. The existing suites assert invariants — a recording locates, a hole is reported as an outage — which catch a pipeline that stopped working but not one that still runs, still locates, and returns a quietly wrong number. This injects known offset, drift, jitter and loss into a synthesised recording, runs the real entry points, and asserts what comes back. 23 checks (2026-09-13T21:55:00-04:00)
- test(analysis): the harness prints a characterization block alongside the assertions — measured boundaries rather than pass/fail. Asserting where the analysis degrades produces a permanently red suite, which teaches you to stop reading it; measuring on every run means the boundary cannot drift unnoticed. Recovery is accurate to 300 ppm drift, 0.5 ms jitter sd and 30% contiguous loss; beyond that, drift reads 16% low at 500 ppm and 81% low at 1000, and jitter saturates near 0.42 ms whatever is injected (2026-09-13T21:55:00-04:00)
- test(analysis): --report draws injected against recovered. A tolerance tells you the error was inside a bound; it does not show a systematic bias that happens to fit. The first run made one visible: every jitter point sits below the diagonal and the gap widens with magnitude, so jitter is under-reported before the assertions catch it — the dangerous direction, since it claims a precision the recorder does not have (2026-09-13T21:55:00-04:00)
- docs: recorded the measured limits in CLAUDE.md, and why contiguous and scattered loss differ so sharply. A 30% stall reads correctly; 15% scattered per-edge reads as 78% missing, because the fingerprint needs four consecutive intervals. This matters less than it appears — every level is held at least 50 ms, so a real recorder cannot miss isolated edges, only a stretch (2026-09-13T21:55:00-04:00)

<!-- version-bumps
[
  { "tool": "PRESYNC", "bump": "minor", "reason": "quantum resolved from the recording; both-edges frame decoding fixed; reports state their assumptions; round-trip accuracy harness with measured limits" }
]
-->

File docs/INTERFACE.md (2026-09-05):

# PRE-Sync — Interface Control Document

Connector pinout, signal levels and the serial command set.

**Generated from the firmware sources — do not edit by hand.**
Regenerate with `python3 tools/gen_interface_doc.py` after changing
`config.h` or the command parser.

## 1. Electrical

| Property | Value | Notes |
|---|---|---|
| Logic family | 5 V CMOS | ATmega32U4, hardware fixed |
| Output HIGH | 5.0 V nominal | |
| Output LOW | 0.0 V nominal | |
| Max current per pin | 40 mA absolute, **20 mA recommended** | ATmega32U4 datasheet |
| Max total across all pins | 200 mA | package limit, not per-pin sum |
| Output impedance | series resistor per channel | sized at build; see BOM |

> **3.3 V equipment**: these outputs are 5 V. Use a divider or level
> shifter. Equipment with TTL inputs (HIGH above 2.4 V) accepts 5 V
> directly.

> **Every output carries the same signal simultaneously.** Each has its
> own driver pin, so loading or shorting one channel does not disturb
> the others.

## 2. Pin assignment

Two board variants. Select Pro Micro with `-DBOARD_PRO_MICRO`.

| Board | Panel outputs | Event channel | Reserved inputs |
|---|---|---|---|
| Arduino Leonardo | 8 | 9 | 2, 3 |
| Pro Micro ATmega32U4 | 8 | 9 | 2, 3 |

### Sync outputs

Eight, matching the enclosure. Chosen so they sit as two contiguous
runs of four on the pin header **and** on only two AVR ports, so the
ISR drives them with two register writes (~0.13 µs) rather than eight
`digitalWrite()` calls (~35 µs, a real skew between channels).

**Pro Micro** — right header, rows 4–11:

| Header | Pins | Port |
|---|---|---|
| A | `21`, `9`, `19`, `18` | PORTF |
| B | `15`, `14`, `16`, `10` | PORTB |

> **A3–A0 are the JTAG pins** (PF4–PF7). The firmware clears JTD in
> `MCUCR` at startup to release them as GPIO. Without that the port
> write is ignored and four channels never toggle — silently, with
> a clean compile and a correct-looking config.

**Leonardo**: `0`, `1`, `4`, `6`, `8`, `10`, `11`, `12`

The Leonardo cannot match the Pro Micro layout: its A0–A5 block is
six contiguous PORTF pins, not eight, so this set keeps the
two-port property and gives up one contiguous run.

Wire each output plus GND to a BNC connector.

### Reserved pins

| Pin | Function | Configuration |
|---|---|---|
| 2 | TRIG IN | `INPUT_PULLUP`, external interrupt capable |
| 3 | FREE/TRIG mode switch | `INPUT_PULLUP` |

| 9 | Event channel output | driven independently of the train |

These are excluded from the sync output set: the trigger pins when
`TRIG_FEATURE` is 1, and the event pin when `EVENT_CHANNEL_ENABLED` is 1.
The `sync_pulse_freerun` build sets it to 0, has no trigger path, and
uses both as additional outputs.

### Pins with a second function

| Pin | Also | Consequence |
|---|---|---|
| 0, 1 | `Serial1` hardware UART | Free to use as outputs: USB is a separate peripheral on the 32U4 and consumes no pins. Reclaim these two if a UART peripheral is ever added. |
| 13 | Onboard LED (Leonardo) | The LED mirrors the sync signal. |
| 2, 3 | INT0/INT1 | The only interrupt-capable pins broken out on a Pro Micro, which is why TRIG IN uses one. |

## 3. Panel connectors

| Connector | Direction | Signal |
|---|---|---|
| OUTPUTS 1-8 (BNC) | out | 0/5 V sync waveform, all identical |
| TRIG IN (BNC) | in | rising edge or level, per trigger mode |
| FREE/TRIG (SPDT) | in | run mode select |
| PWR (barrel) | in | DC input |
| GND (10-32 screw) | — | chassis / tether point |

### TRIG IN

BNC centre through a ~1 kΩ series resistor to the input pin, which is
`INPUT_PULLUP`. An idle master holding 0 V arms the input; it must sit
LOW for `TRIG_ARM_LOW_MS` = 20 ms before
a rising edge counts, so an unconnected jack cannot false-trigger.

### Mode switch

Common to the mode pin; the **FREE RUN throw leaves the pin OPEN** and
the TRIG RUN throw closes it to GND.

This polarity is deliberate. The pin is `INPUT_PULLUP`, so an unwired
or disconnected switch floats HIGH and reads FREE RUN — the box emits.
A switch that fails open fails into working. The opposite convention
leaves the box silent and waiting for a trigger that never arrives,
which is only discovered later, in analysis, when nothing aligns.

## 4. Signal

| Parameter | Default | Define |
|---|---|---|
| HIGH duration | 50–500 ms | `DEFAULT_M{IN,AX}_HIGH_MS` |
| LOW duration | 50–500 ms | `DEFAULT_M{IN,AX}_LOW_MS` |
| Duration quantum | 5 ms | the finest step the generator emits |
| PRNG seed | 42 | `DEFAULT_PRNG_SEED` |

Durations are drawn by a xorshift32 PRNG. **The waveform is fully
determined by (seed, configuration)**, so it can be regenerated offline
and used as ground truth — which is what the analysis toolkit does.

### Timecode frames

Every `DEFAULT_TC_INTERVAL_S` = 10 s the
train is interrupted by one frame carrying:

    [16-bit run ID][32-bit elapsed seconds][4-bit checksum]

| Element | Value | Define |
|---|---|---|
| Pulse width | 5 ms | `TC_PULSE_MS` |
| Preamble | 3 pulses, 10 ms gaps | `TC_PREAMBLE_GAP_MS` |
| Bit = 0 | 15 ms gap | `TC_GAP_ZERO_MS` |
| Bit = 1 | 25 ms gap | `TC_GAP_ONE_MS` |
| Lead-in | 20 ms forced LOW | `TC_LEADIN_MS` |

The run ID is an EEPROM counter incremented on every PRNG restart, so
(run ID, elapsed) identifies every moment the box has ever emitted,
across power cycles. Frames start exactly on the interval tick: a
decoded frame's first edge marks exactly `elapsed` seconds of generator
time, which gives absolute position with no pattern search.

Frames consume no PRNG draws, so the hybrid signal remains fully
reproducible.

**Reserved-gap rule**: keep minimum HIGH + minimum LOW well above
`TC_PULSE_MS` + `TC_GAP_ONE_MS` (100 vs 30 ms by
default) so the random section can never imitate frame timing.

## 5. Trigger modes

Runtime-settable, so one firmware serves several experimental designs
and a host application can change behaviour over serial.

| Mode | `trigmode` | Behaviour |
|---|---|---|
| `TRIG_MODE_EDGE_START` | `start` | A rising edge starts a run; further edges ignored until the mode switch is cycled. |
| `TRIG_MODE_EDGE_TOGGLE` | `toggle` | Rising edge starts, next edge stops, and so on. |
| `TRIG_MODE_LEVEL_GATE` | `gate` | Runs while TRIG IN is HIGH. The run clock restarts on each rising edge, so every gated segment is its own run with its own ID. |

### Lead-in marker

Optionally emit one clean pulse, hold LOW for a fixed pause, then begin
the train. A single unambiguous flash is far easier to find in video
than a pseudo-random train, so a camera recording an LED can be aligned
off that one event without decoding anything.

| Parameter | Default | Define |
|---|---|---|
| Enabled | off | `DEFAULT_LEADIN_PULSE_ENABLED` |
| Pulse width | 50 ms | `DEFAULT_LEADIN_PULSE_MS` |
| Pause | 500 ms | `DEFAULT_LEADIN_PAUSE_MS` |

The run clock starts at the **leading edge of the marker pulse**, so
embedded timecode stays referenced to the trigger instant, and the
pause is a known constant.

## 6. Event channel (pin 9)

Carries events instead of the sync train. Every trigger arriving on
TRIG IN emits a marker here; the remaining outputs carry the train
untouched.

    [MARK][gap][payload symbols, MSB first][gap]

| Element | Duration |
|---|---|
| MARK (the event) | 200 ms |
| Gap between symbols | 50 ms |
| Symbol = 0 | 50 ms |
| Symbol = 1 | 100 ms |
| Payload | 8-bit per-run event counter |
| Total marker | 1050–1450 ms |

**The MARK's leading edge is the event**, at interrupt latency
(~4 µs). Everything after it is an identifier and does not affect
timing, so accuracy is the same regardless of the payload.

The counter is per-run: event 3 of run 7 is unambiguous. It lets a
camera that saw only this channel tell one trigger from another,
which is the one thing a plain event flag cannot do.

**Close-spaced triggers**: a new trigger aborts a marker still in
progress. The MARK always fires; the counter is best-effort. Event
timing is never sacrificed to finish an identifier, and a decoder
reports the truncated marker with its exact timestamp rather than
guessing a number from partial bits.

Widths are sized for the slowest recorder that might see this: at
24 fps a frame is 41.7 ms, and a pulse must exceed one full frame
interval to be caught regardless of phase. The 200 ms mark spans
4.8 frames; the symbols span 1.2 and 2.4.

Decode with `presync.decode_events()`.

## 7. Serial interface

USB CDC (`Serial`), which consumes no GPIO. Commands are newline
terminated. Changes take effect immediately; `save` persists them.

| Command | Effect |
|---|---|
| `high <min> <max>` | HIGH duration range, ms |
| `low <min> <max>` | LOW duration range, ms |
| `seed <n>` | PRNG seed; same seed = same sequence |
| `tc on|off` | embedded timecode frames |
| `tcint <s>` | seconds between frames (min 2) |
| `trigmode start|toggle|gate` | what TRIG IN does |
| `mark on|off` | lead-in marker pulse before the train |
| `markms <pulse> <pause>` | marker width and LOW hold, ms |
| `save` | persist current config to EEPROM |
| `reset` | restore compile-time defaults |
| `start` | begin emitting |
| `stop` | stop emitting (outputs LOW) |
| `restart` | restart the PRNG; increments run ID |
| `pintest` |  |
| `config` | print the running configuration |
| `help` | list commands |

## 8. Persistence

| Item | Address | Notes |
|---|---|---|
| Config block | 0 | validated by magic byte `0xA9` |
| Run ID counter | 64 | separate, so `save` never touches it; wraps at 65535 |

Changing `EEPROM_MAGIC` forces a reset to compile-time defaults on the
next boot.

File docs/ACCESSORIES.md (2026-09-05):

# PRE-Sync accessories

Small powered pods that adapt the box's outputs to recorders it cannot drive
directly. All are optional; the box is complete without them.

## Event fan-out pod (1→4)

**Purpose.** The event channel is a single BNC, and a session often needs the
same event delivered to several recorders at once — a camera, a DAQ, a
stimulus PC. Daisy-chaining from one output loads it unpredictably and the
edge degrades differently at each tap, which is exactly the kind of unknown
this system exists to remove.

**Function.** One BNC in, four buffered BNC out, all carrying the same signal.
Each output is independently driven, so loading or shorting one does not
disturb the others — the same guarantee the main box makes for its eight
channels, for the same reason.

**Why powered.** A passive splitter divides the signal and its edge rate
degrades with every branch. A buffered pod regenerates full-amplitude edges on
each output, so the fourth device sees the same rise time as the first. Skew
between outputs is then a fixed, measurable constant rather than a function of
what happens to be plugged in.

| Parameter | Target |
|---|---|
| Inputs | 1 × BNC |
| Outputs | 4 × BNC, independently buffered |
| Propagation delay | < 50 ns, matched across outputs |
| Output-to-output skew | < 10 ns (**TBM**) |
| Input impedance | high-Z, so it does not load the source |
| Supply | 5 V, barrel or USB |
| Logic | 5 V CMOS, matching the main box |

**Implementation note.** A single hex buffer (74HC541 or similar) covers this
with two gates spare. No microcontroller: the pod must not add timing
uncertainty of its own, and anything with firmware eventually has jitter.

**Skew must be measured, not assumed.** The propagation delay is common to all
four outputs and therefore harmless — it shifts every recorder equally. The
skew *between* outputs is not, because it appears as a fixed offset between
two recorders that no analysis can distinguish from a real one. Measure it
once per pod and record it on the unit.

## LED converter

**Purpose.** Makes a channel visible to cameras that have no electrical input.

Plugs into either the sync train (1–7) or the event channel (8), or two units
into both. On the event channel the 200 ms mark is unmistakable at 24 fps; on
the train, the 50–500 ms pulses are followed easily by any camera.

| Parameter | Target |
|---|---|
| Input | 1 × BNC, high-Z |
| Output | high-brightness LED, wide viewing angle |
| Turn-on delay | < 1 ms (**TBM**) |
| Supply | 5 V |

**Turn-on delay is a real offset**, not a rounding error: it appears between
the electrical signal and the optical one, so a session mixing cameras and
DAQs inherits it. Measure it and record it, the same as pod skew.

## Heat-set inserts

The gooseneck screws into a brass heat-set insert at each end — the LED puck
base and the LED head take the same one, so the gooseneck fits either way
round.

| | |
|---|---|
| Part | McMaster **151030**, `INS 29/250-20/.312L`, brass |
| Thread | 1/4"-20 |
| Insert OD | 0.290 in = **7.37 mm** |
| Insert length | 0.312 in = **7.92 mm** |
| Printed hole | **7.07 mm** (OD − 0.3) |
| Pocket depth | 9.5 mm |

**The hole is deliberately smaller than the insert.** A heat-set insert is
pressed in with a soldering iron: the plastic melts and flows into the
knurling, and that interference is what holds it. A hole at or above the
insert's OD gives the knurl nothing to bite, and the insert spins under the
first real torque — which, on a gooseneck, is every time it is repositioned.
0.3 mm under leaves 0.15 mm per side to melt: enough to grip, not enough to
split the boss.

### Installing

1. Fit a **soldering iron insert tip** if you have one; otherwise a
   conical tip works. Set **200–230 °C** for PETG, 180–200 °C for PLA.
   Too hot scorches and the insert sinks crooked; too cold and it stalls
   part-way and cannot be pushed further without tearing the boss.
2. Rest the insert on the hole. The printed pocket has a **0.8 mm lead-in
   chamfer** so it self-centres — start it square there rather than by eye.
3. Press down slowly and **check squareness from two directions** at the
   halfway point. A crooked insert cannot be straightened once it cools; it
   has to be melted back out and the boss is usually ruined.
4. Stop when the insert is **flush or 0.1–0.2 mm below** the surface. Proud
   inserts stop the gooseneck collar from seating flat.
5. Let it cool fully before threading anything in. Brass holds heat, and
   tapping a thread into softened plastic strips the grip you just made.

If an insert does spin later, the fix is a larger insert into a drilled-out
boss, not glue — adhesive on a rotating joint fails again under the same load.

## Status

All accessories are **specified, not built**. Targets marked **TBM** require a
built unit. See `docs/TEST_PROCEDURE.md` for the measurement method.

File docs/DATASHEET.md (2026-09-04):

# PRE-Sync — Datasheet

A pseudo-random square-wave generator for post-hoc alignment of independent
recording systems.

**Status: preliminary.** Values marked *TBM* (to be measured) are design
intent, not measurements. See `docs/TEST_PROCEDURE.md`.

## Description

PRE-Sync emits a pseudo-random square wave simultaneously on up to 18
independently driven outputs. Because the waveform is fully determined by
(seed, configuration), it can be regenerated offline and used as ground truth:
every recorded edge has a known true time, and the difference is the
recorder's error.

That distinguishes it from a plain trigger pulse. A single pulse marks one
instant; a non-repeating pattern lets any segment of a recording be located
absolutely, so offset, clock drift, jitter and data loss can be separated and
measured rather than assumed.

Optional embedded timecode frames carry a run ID and elapsed seconds, giving
absolute position with no pattern search and identifying which run was
recorded.

## Absolute maximum ratings

| Parameter | Min | Max | Unit |
|---|---|---|---|
| Supply voltage (barrel) | 7 | 12 | V |
| Current per output pin | — | 40 | mA |
| Total current, all pins | — | 200 | mA |
| Operating temperature | 0 | 50 | °C |

Exceeding these may cause permanent damage. Sustained operation should stay
within the recommended conditions below.

## Recommended operating conditions

| Parameter | Typ | Notes |
|---|---|---|
| Supply voltage | 9 V | or USB 5 V |
| Current per output | ≤ 20 mA | ATmega32U4 recommendation |
| Output load | ≥ 1 kΩ | high-impedance recorder inputs |

## Electrical characteristics

| Parameter | Value | Notes |
|---|---|---|
| Output HIGH | 5.0 V nominal | 5 V CMOS, hardware fixed |
| Output LOW | 0.0 V nominal | |
| Rise time | *TBM* | into a realistic load |
| Fall time | *TBM* | |
| Channel-to-channel skew | *TBM* | across all outputs |
| Output impedance | series resistor per channel | value *TBM* |

> **3.3 V equipment**: outputs are 5 V. Use a divider or level shifter.
> TTL inputs (HIGH above 2.4 V) accept 5 V directly.

## Timing characteristics

| Parameter | Value | Notes |
|---|---|---|
| Pulse duration range | 50–500 ms | HIGH and LOW independently drawn |
| Duration quantum | 5 ms | the finest step emitted |
| Timecode interval | 10 s | when enabled |
| Timecode pulse width | 5 ms | |
| Generator clock accuracy | *TBM* | bounds every alignment |
| Trigger arm time | 20 ms | LOW hold before an edge counts |

## Interfaces

| Connector | Qty | Type |
|---|---|---|
| Sync output | 8 wired (18 available) | BNC bulkhead |
| TRIG IN | 1 | BNC bulkhead |
| Mode select | 1 | SPDT toggle |
| Power | 1 | 5.5×2.1 mm barrel |
| Chassis ground | 1 | 10-32 screw |
| Configuration | 1 | USB CDC serial |

Full pinout, signal levels and command set: `docs/INTERFACE.md`.

## Mechanical

| Parameter | Value |
|---|---|
| Internal envelope | 168 × 45 × 31 mm |
| Wall thickness | 3 mm |
| Enclosure | 3D printed, four parts |
| Mass | *TBM* |

## Failure behaviour

Design choices that determine how the device fails, which for a timing
reference matters more than how it performs when everything works:

- **A missing or failed-open mode switch reads FREE RUN**, so the box emits.
  Silence is the worst failure available here, because it is only discovered
  later, in analysis, when nothing aligns.
- **An unconnected TRIG jack cannot false-trigger**: the input must sit LOW
  for 20 ms before a rising edge counts.
- **Each output has its own driver pin**, so loading or shorting one channel
  does not disturb the others.
- **The run ID increments on every PRNG restart** and persists in EEPROM, so
  two runs are never confused even though a fixed seed makes their waveforms
  identical.

## Reproducibility

The emitted waveform is regenerated bit-identically by three independent
implementations (Python, MATLAB, R) in `sync_pulse_generator/utils/`.

## Documents

| Document | Contents |
|---|---|
| `docs/INTERFACE.md` | Pinout, levels, serial commands |
| `docs/BOM.csv` | Bill of materials |
| `docs/wiring/presync-schematic.svg` | Electrical schematic |
| `docs/wiring/presync-harness.png` | Panel wiring |
| `docs/TEST_PROCEDURE.md` | Acceptance tests |
| `docs/api/` | Analysis toolkit API |

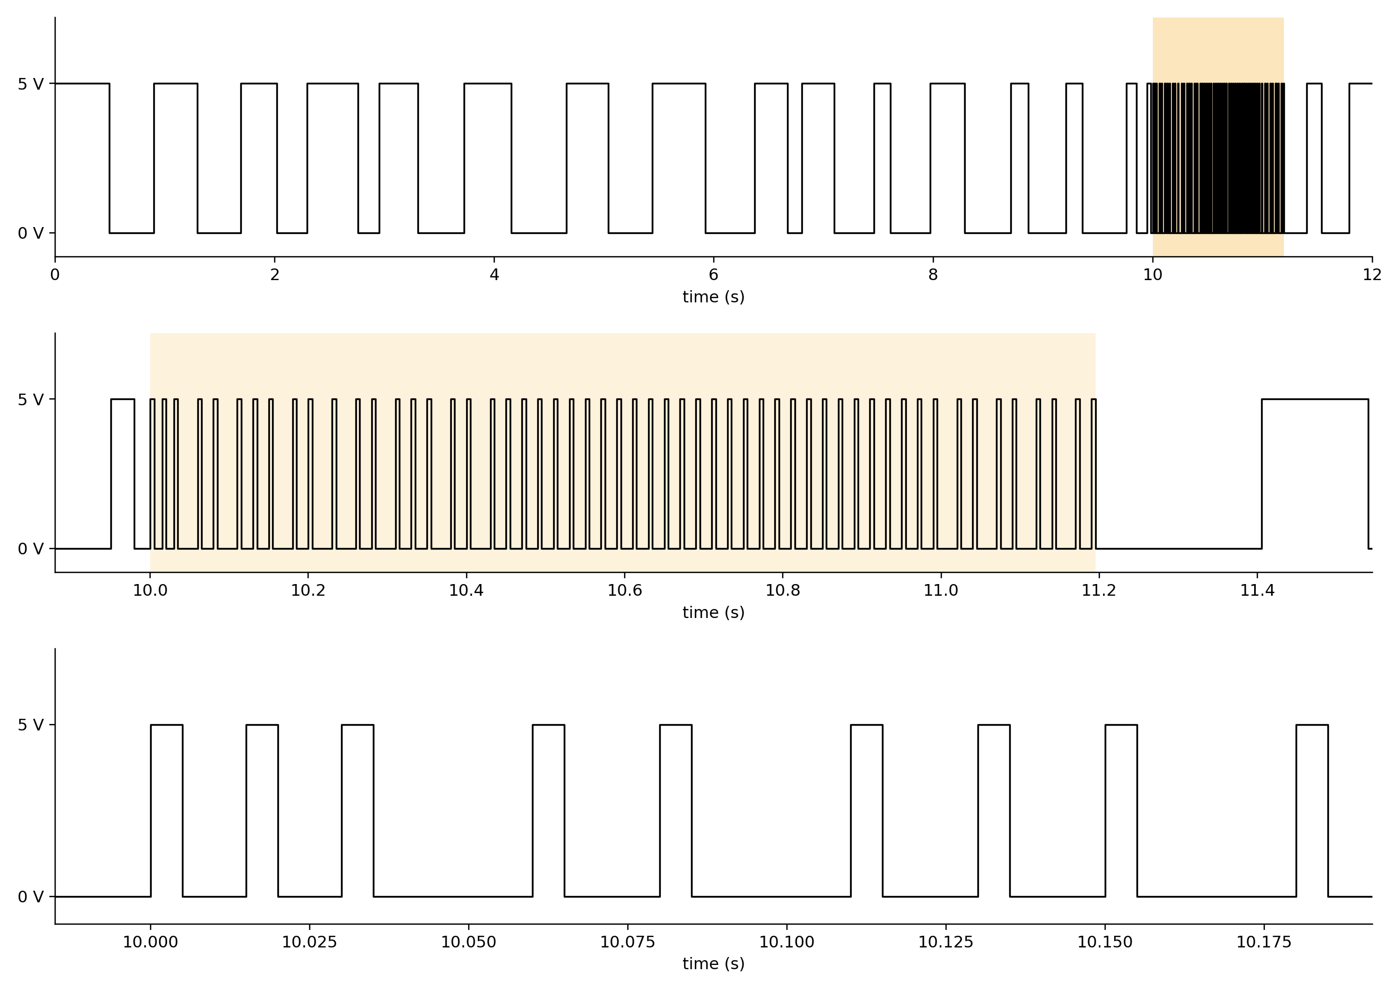
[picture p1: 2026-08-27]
sync_pulse_generator/docs/timecode_figure_bare.png

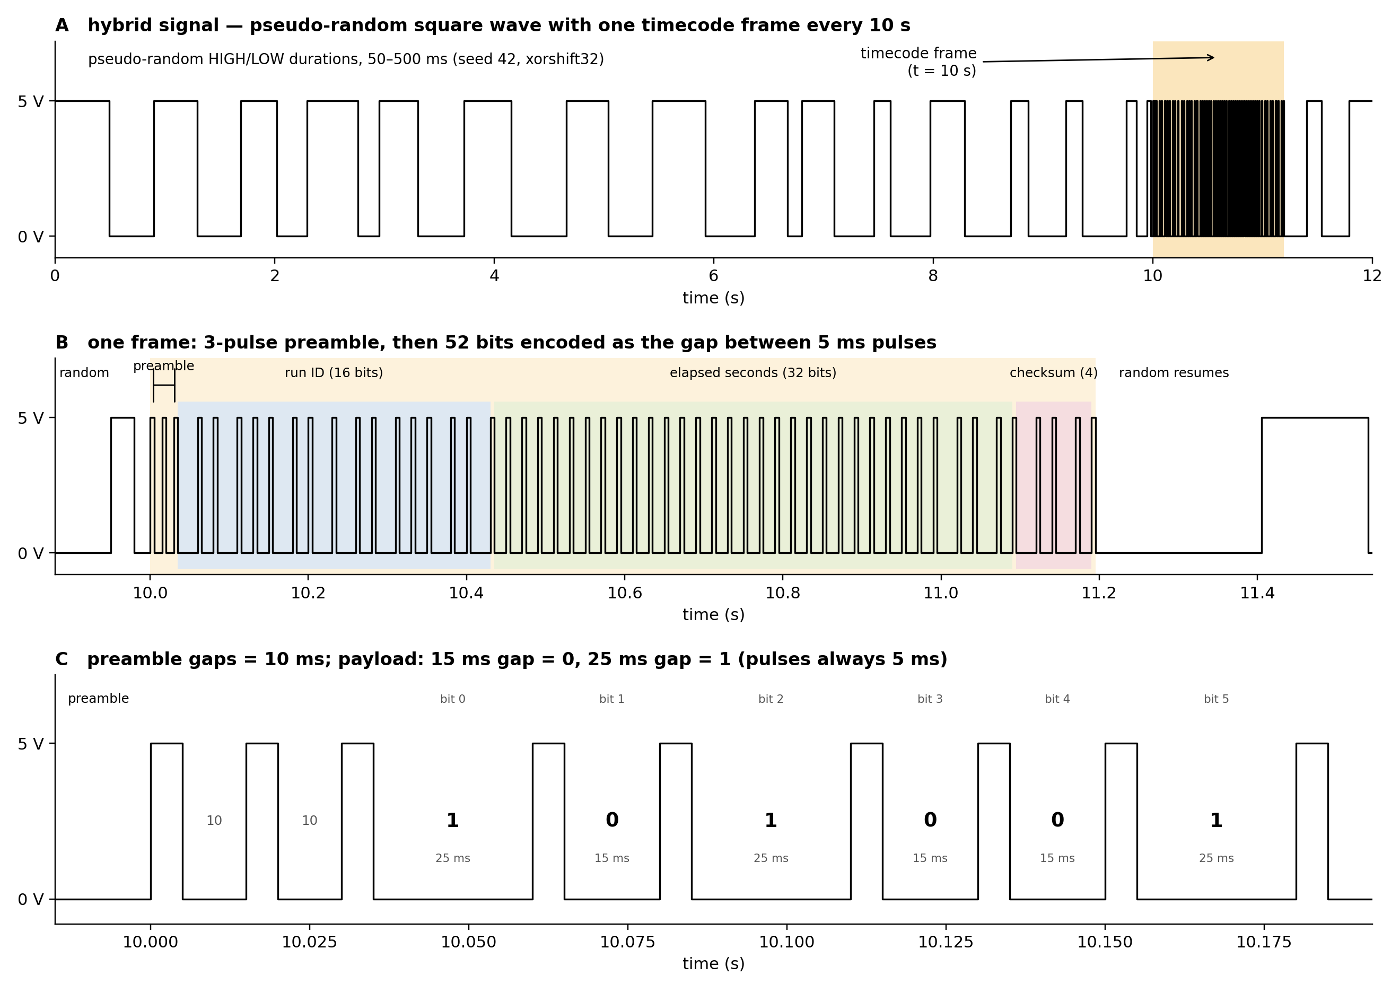
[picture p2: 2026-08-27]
sync_pulse_generator/docs/timecode_figure.png

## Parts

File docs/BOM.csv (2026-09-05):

ref | qty | item | specification | mpn | supplier | unit_price | currency | price_date | notes
U1 | 1 | Microcontroller board | Pro Micro ATmega32U4, USB-C, 5V/16MHz |  |  |  |  |  | Leonardo also supported; -DBOARD_PRO_MICRO selects 18-pin variant
J1-J8 | 8 | BNC connector | Panel-mount bulkhead, threaded, 3/8-32, 9.7mm panel hole |  |  |  |  |  | Sync outputs. Hole dia from trigger-box.scad bnc_d
J9 | 1 | BNC connector | Panel-mount bulkhead, threaded, 3/8-32, 9.7mm panel hole |  |  |  |  |  | TRIG IN. Same part as J1-J8
J10 | 1 | DC barrel jack | Panel-mount, 5.5x2.1mm, 11.5mm bushing |  |  |  |  |  | PWR. Hole dia from barrel_d
SW1 | 1 | Toggle switch | SPDT, 6mm bushing, panel mount | MTS-102 |  |  |  |  | Hole 6.5mm fit-tested. FREE throw OPEN, TRIG throw to GND
R1-R8 | 8 | Resistor | Series output resistor, 1/4W, value TBD |  |  |  |  |  | VERIFY: value not yet fixed. Sets output impedance
R9 | 1 | Resistor | 1k ohm, 1/4W |  |  |  |  |  | TRIG IN series protection
D1 | 1 | LED | Panel indicator, 3mm or 5mm |  |  |  |  |  | Face LED. Confirm bezel dia against led_bezel_d
R10 | 1 | Resistor | LED series, value depends on D1 Vf
PCB1 | 1 | Prototyping board | Perfboard, size TBD |  |  |  |  |  | VERIFY: pcb_dx=76 pcb_dy=15 post spacing UNVERIFIED against real board
MECH1 | 1 | Enclosure frame | 3D printed, PETG or ABS |  |  |  |  |  | trigger-box.scad part=frame. Prints rim-down, no supports
MECH2 | 1 | Enclosure face plate | 3D printed |  |  |  |  |  | part=face
MECH3 | 1 | Enclosure face art | 3D printed, contrast filament |  |  |  |  |  | part=face_art
MECH4 | 1 | Enclosure lid | 3D printed |  |  |  |  |  | part=lid. Bottom when deployed
MECH5 | 1 | Copper foil tape | Adhesive, for interior shielding |  |  |  |  |  | Single ground point at the 10-32 screw
HW1 | 1 | Ground screw | 10-32, with ring terminal |  |  |  |  |  | Right end wall, chassis/tether point
HW2 | 4 | Screw | M3 x 12 self-tapping, countersunk head |  |  |  |  |  | face plate to corner posts (3 mm through, ~9 mm engagement). 3.4 mm clearance / 2.8 mm pilot
HW3 | 4 | Screw | M3 x 16 self-tapping, countersunk head |  |  |  |  |  | lid to corner posts — LONGER than the face screws: 3 mm plate + 3 mm lip to pass before engaging
HW4 | 4 | Screw | M2.5 x 8 self-tapping, pan head |  |  |  |  |  | PCB to hanging posts. Pilot 2.2 mm x 5.5 deep
WIRE1 | 1 | Hookup wire | 22-24 AWG stranded, multiple colours |  |  |  |  |  | See docs/WIRING.md for the harness
HW5 | 8 | Screw | M3 x 12 self-tapping, countersunk head |  |  |  |  |  | pod top + base plates, 4 each. Same as HW2 — order together
HW6 | 2 | Mounting screw | #8 or M4, pan/round head, head dia <= 8.0 mm |  |  |  |  |  | wall mount via keyholes. NOT into the print: head passes an 8.6 mm hole, shank rides a 4.5 mm slot. Counterbored so the head sits below the face
HW7 | 2 | Heat-set insert | Brass, 1/4"-20, 0.290 in OD x 0.312 in long | 151030 | McMaster-Carr |  |  |  | gooseneck, one per end. Printed hole 7.07 mm — UNDERSIZED on purpose, see docs/ACCESSORIES.md

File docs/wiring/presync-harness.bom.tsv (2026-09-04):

Id | Description | Qty | Unit | Designators
1 | Cable, 1 x 22 AWG | 0 | m | W_CHASSIS
2 | Cable, 2 x 22 AWG | 0 | m | W_PWR
3 | Cable, 2 x 24 AWG | 0 | m | W_MODE, W_TRIG
4 | Cable, 8 x 24 AWG | 0 | m | W_GND, W_OUT
5 | Connector, BNC, bulkhead, 2 pins | 9 |  | OUT1, OUT2, OUT3, OUT4, OUT5, OUT6, OUT7, OUT8, TRIG
6 | Connector, DC barrel, 5.5x2.1 panel, 2 pins | 1 |  | PWR
7 | Connector, Ground screw, 10-32, 1 pins | 1 |  | GNDLUG
8 | Connector, Pro Micro ATmega32U4, male header, 13 pins | 1 |  | MCU
9 | Connector, SPDT toggle, MTS-102, 3 pins | 1 |  | MODE

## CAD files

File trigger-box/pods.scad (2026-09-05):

// ============================================================================
// pods.scad — PRE-Sync inline accessories: round Ø60 pucks on a shared body.
//
//   ring       — GAIN puck wall, open both ends: BNC IN and OUT on opposite
//                sides (inset labels), 4 internal posts with screw pilots at
//                both ends, 40 tall (the pot body clears the BNC tails).
//   ring_in    — LED / SOUND puck wall: IN jack only, 28 tall.
//   base       — bottom plate: centered keyhole (slot vertical, so the BNCs
//                run left-right when hung) — common to all three pucks.
//   top_gain   — GAIN puck top: pot hole, "GAIN", arc arrow LOW -> HIGH.
//                Inside: IN center -> pot end, wiper -> OUT center, other
//                end -> shield. High-impedance loads only.
//   top_led    — LED puck top: 1/4"-20 nut trap for a hollow GOOSENECK (mic /
//                lamp gooseneck, wires run inside, holds any position).
//   led_head   — screws on the gooseneck's far end: 10mm LED press-fit
//                with the panel-ring seat, wire passage through.
//   led_head_5mm — 5mm LED variant: LED pushes in from the back (same side
//                as the wire passage) through a straight bore until its
//                flange catches on a narrower front opening, flush at front.
//   top_sound  — SOUND puck top: pocket for a 5V ACTIVE piezo buzzer, grille,
//                VOL pot, and a LEVEL/EDGE toggle: sound for the whole HIGH,
//                or one short blip on each rising edge (RC one-shot inside).
//
// All parts print flat as exported, no supports. Labels inset (Futura
// Medium, same treatment as the box). Screws: M3 self-tappers, countersunk.
//
//   openscad -o pod-ring.stl -D 'part="ring"' pods.scad   (etc.)
// ============================================================================

include <lib/nyk-lib.scad>

part = "ring";   // ring | ring_in | base | top_gain | top_led | led_head | led_head_5mm | top_sound | preview

// ---- Puck body --------------------------------------------------------------
puck_d   = 60;
wall     = 3;
body_h    = 40;     // GAIN ring height (pot body clears the BNC tails)
body_h_in = 28;     // LED / SOUND ring height (IN jack only)
bnc_d    = 9.7;
bnc_z    = 13;      // BNC centerline above the ring's base end
pot_d    = 7.2;
led_d    = 10.4;    // 10mm LED press-fit
led_ring_d = 14;    // LED panel-ring seat (inset), matches the box face
art_recess = 1.2;

// 5mm LED — MEASURED.
// 5.22 mm is the body diameter. The head's front mouth is 4.9 mm, narrower
// than the body, so the LED loads from the BACK and stops there with its dome
// protruding through. The bore tapers down to the mouth rather than stepping,
// so the LED self-centres as it seats instead of relying on a ledge held to a
// tolerance the printer may not reach.
led5_d        = 5.22;   // body diameter. MEASURED.
led5_mouth_d  = 4.9;    // front opening: the dome pokes through, the body stops
led5_taper_h  = 2.5;    // depth over which the bore narrows to the mouth
led5_seat_h   = 2.0;    // snug bore holding the body square. Short on
                        // purpose: the LED only needs squaring, not
                        // gripping along its length, and every extra mm
                        // here is a mm the head grows by.
// Behind the seat the bore opens out. The LED's legs run back from its base
// and will not thread down a bore sized to the body itself -- at 0.25 mm per
// side there is nowhere for them to go. This relief is the wire path from the
// LED cavity into the gooseneck socket.
led5_relief_d = 9.0;
led5_relief_h = 1.5;    // length of the relief section
                        // lip. 0.15 clearance, 0.085 mm of ledge per side.

// posts: 4 at 45° off the BNC axis, sunk into the wall
post_d   = 7;
post_r   = puck_d/2 - wall - post_d/2 + 1.5;
post_angles = [45, 135, 225, 315];
pilot_d  = 2.8;
screw_d  = 3.4;

// keyhole (base plate)
key_head_d = 8.6;
key_slot_w = 4.5;
key_slide  = 9;
key_pad_d  = 16;
key_pad_h  = 3;
// Counterbore on the OUTSIDE face so a mounted screw head sits BELOW the
// bottom of the pod. Without it the head stands proud of an otherwise flat
// disc and the pod rocks on it whenever it is set on a bench. The pod is
// wall-mounted in use but spends most of its life on a table, which is where
// the defect shows.
key_cbore_d = 15;
key_cbore_h = 2.0;   // of wall = 3, leaving 1 mm carrying the slot

// ---- Gooseneck mount --------------------------------------------------------
// 1/4"-20 male ends (the common mic/lamp gooseneck thread), screwing into a
// HEAT-SET BRASS INSERT at each end. gn_insert_d is the hole for the INSERT,
// not for the thread.
//
// BOTH ENDS USE THE SAME MOUNT. The LED head and the puck base take an
// identical insert, so the gooseneck screws into either and the two are
// interchangeable — one spare gooseneck fits everything, and there is no
// handedness to get wrong during assembly.
//
// The measured 12.75 mm barrel on some goosenecks is the knurled COLLAR that
// sits against the mounting surface, not a spigot to be bored for. The thread
// is what carries the load; the collar just bottoms out. boss_d is sized to
// give that collar a flat landing without the boss becoming a bore.
// Insert: McMaster 151030 — INS 29/250-20/.312L, brass, heat/ultrasonic.
//   29/250 = 0.290" OD  = 7.37 mm
//   -20    = 1/4"-20    (the gooseneck thread)
//   .312L  = 0.312" long = 7.92 mm
//
// THE HOLE IS SMALLER THAN THE INSERT. A heat-set insert is pressed in with a
// soldering iron: the plastic melts and flows into the knurling, and that
// interference is what holds it. A hole at or above the insert's OD gives the
// knurl nothing to bite and the insert spins under the first real torque —
// which on a gooseneck is every time it is repositioned. 0.3 mm under the OD
// leaves 0.15 mm per side to melt, enough to grip without splitting the boss.
gn_thread_d  = 6.9;    // wire passage / thread clearance BELOW the insert
gn_insert_od = 7.37;   // the insert itself (McMaster 151030)
gn_insert_d  = 7.07;   // the HOLE: OD - 0.3 interference for heat-setting
gn_insert_len = 7.92;  // the insert itself
gn_insert_h  = 9.5;    // bore depth: insert + room for displaced plastic
gn_collar_d  = 12.75;  // knurled collar that lands on the boss face

// The LED HEAD's socket for the gooseneck end. 12.75 mm was measured off the
// gooseneck; the socket is a plain bore with a lead-in chamfer.
gn_barrel_d   = 12.75;
gn_barrel_fit = 0.20;
gn_barrel_h   = 12;     // bore depth

// The boss face must be wider than the collar so the collar seats flat on it
// rather than overhanging an edge.
boss_d = gn_collar_d + 2*4;   // 20.75 -> 4 mm of landing all round

// active buzzer (VERIFY against the part you buy)
buzzer_d    = 23.5;   // 23mm 5V active piezo — loud, sounds while HIGH
buzzer_h    = 10;
grille_hole = 2.2;
switch_d    = 6.5;    // MTS-102 SPDT toggle: LEVEL / EDGE

// ---- Labels -----------------------------------------------------------------
label_size   = 4.6;
label_font   = "Futura:style=Medium";
label_deboss = 0.8;
label_fat    = 0.2;
module fat_text(s, size = label_size) {
  offset(r = label_fat)
    text(s, size = size, font = label_font, halign = "center", valign = "center");
}
// deboss 2D children into the top face of a plate of thickness `wall`
// Heat-set insert pocket, cut downward from z=`top`.
// The chamfer matters more than it looks: without a lead-in the insert has
// to be started perfectly square by hand while the iron is already melting
// plastic, and a crooked insert cannot be straightened once it cools. The
// cone lets it self-centre for the first half millimetre.
module insert_pocket(top) {
  translate([0, 0, top - gn_insert_h])
    cylinder(d = gn_insert_d, h = gn_insert_h + 0.01);
  translate([0, 0, top - 0.8])
    cylinder(d1 = gn_insert_d, d2 = gn_insert_d + 1.2, h = 0.81);
}

module top_deboss() {
  translate([0, 0, wall - label_deboss]) linear_extrude(label_deboss + 0.01) children();
}
// deboss 2D children into the ring's outer wall at angle `a` (0 = +x),
// centered at height z; extruded radially inward (deeper than the wall
// curvature so the whole glyph cuts)
module wall_deboss(a, z) {
  rotate([0, 0, a]) translate([puck_d/2 + 0.01, 0, z])
    rotate([90, 0, -90]) linear_extrude(label_deboss + 0.9) mirror([1, 0, 0]) children();
}
// countersunk screws on the z=0 face (for plates whose outside is z=0)
module plate_screws_bottom() {
  for (a = post_angles) rotate([0, 0, a]) translate([post_r, 0, 0]) {
    translate([0, 0, -0.5]) cylinder(d = screw_d, h = wall + 1);
    translate([0, 0, -0.01]) cylinder(d1 = screw_d * 2, d2 = screw_d, h = wall * 0.7);
  }
}
// deboss 2D children into the z=0 face, mirrored so they read from outside
module bottom_deboss() {
  translate([0, 0, -0.01]) linear_extrude(label_deboss + 0.01) mirror([1, 0, 0]) children();
}
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

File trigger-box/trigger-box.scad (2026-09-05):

// ============================================================================
// trigger-box.scad — PRE-Sync: enclosure for sync_pulse_generator (32U4)
//
// THREE-PART BUILD (no supports anywhere):
//   frame    — the walls + corner posts, open at both ends. 8 BNC outputs on
//              the front (one Arduino pin each, no pots), TRIG IN + FREE/TRIG
//              switch on the back, PWR barrel left end, ground screw centered
//              on the right end, PCB posts inside the rear wall.
//   face     — flat display plate that screws onto one end (countersunk M3
//              self-tappers into the corner posts): Neuromechanics Lab icon
//              + "PRE-Sync" wordmark as a 1.2mm inset whose FLOOR is colored
//              (face_art = the 0.6mm filament-1 slab under the recess), and
//              the panel-mount LED through the neuron's soma.
//   lid      — screws onto the other end; keyhole mounts + attribution.
//
// ALL lettering is inset (debossed) with fattened bold strokes so it prints
// smooth. Deployed: face up, lid down, hung by the lid keyholes.
//
// PRINT — every part flat, as exported, no rotation, no supports:
//   frame     either end down (walls only)
//   face      face UP (as modeled) — import face + face_art into ONE Bambu
//             Studio object: face_art -> filament 1 (orange), face -> 2.
//             Color change = 3 layers just below the top surface.
//   lid       flat as-is
//
// Parts:
//   openscad -o frame.stl     -D 'part="frame"'     trigger-box.scad
//   openscad -o face.stl      -D 'part="face"'      trigger-box.scad
//   openscad -o face_art.stl  -D 'part="face_art"'  trigger-box.scad
//   openscad -o lid.stl       -D 'part="lid"'       trigger-box.scad
//   openscad -o hole_test.stl -D 'part="hole_test"' trigger-box.scad
// ============================================================================

include <lib/nyk-lib.scad>

part = "frame"; // "frame" | "face" | "face_art" | "lid" | "hole_test" | "preview"

// ---- Cavity -----------------------------------------------------------------
inner = [168, 45, 31];
wall  = 3;            // 3mm all walls (keyhole pads on the lid go thicker)
rad   = 3;

// ---- Panel hardware (VERIFY on hole_test) -----------------------------------
bnc_d     = 9.7;   // threaded bulkhead BNC, 3/8" barrel
switch_d  = 6.5;   // SPDT toggle (MTS-102 — 6mm bushing, 6.5 hole fit-tested)
barrel_d  = 11.5;  // 5.5x2.1 panel-mount barrel jack bushing
led_d     = 10.4;  // bare 10mm LED pressed in from the inside; its flange
                   // sits against the plate interior (VERIFY on hole_test)
led_ring_d = 14;   // the LED's panel-mount ring (~11.5 measured) + a style margin:
                   // a circular INSET of this diameter around the hole, same
                   // depth as the art, so the ring sits in it near flush on
                   // the soma's orange floor (VERIFY on hole_test)
led_bezel_d = 0;   // 0 = no raised/flat landing (ring is inset instead)

// ---- Front row (+Y): 8 BNC outputs ------------------------------------------
// 19mm pitch. In the printed/deployed (face-up) box, viewed from the front,
// output 1 is LEFT-most = smallest model x (render-verified).
n_out      = 8;
out_pitch  = 19;
front_z    = 17;
function out_x(i) = (i - (n_out - 1)/2) * out_pitch;   // i = 0..n_out-1

// ---- Rear (-Y): TRIG input + mode switch ------------------------------------
// Whole group lives in the left half of the wall; the right half carries the
// PCB posts/board. Toggle body y-clears the barrel jack's inward protrusion.
ctrl_cx    = -44;   // group center (CONTROL header rides here too)
trig_x     = ctrl_cx + 17;   // IN jack (deployed viewed-left of the toggle)
mode_x     = ctrl_cx - 17;   // toggle; TRIG/RUN label on the BNC side
rear_z     = 17;

// ---- Left end (-X): power barrel, centered ----------------------------------
barrel_z   = 17;

// ---- Face (floor exterior, z=0): icon + LED + wordmark ----------------------
// Icon source: logo-icon-filled.svg (logo-icon.svg with all outline holes
// filled so every shape is a solid inset; filtered from NeuromechanicsLabLogo_noface.ai —
// background + text stripped, 26 paths). MEASURED imported bbox (pt units
// import at 0.3528mm/pt): x 15.80..142.23, y 28.62..83.69.
icon_w      = 95;                 // printed icon width
icon_cx     = -22;                // icon center on the face
art_recess  = 1.2;                // recess depth into the face
art_h       = 0.6;                // colored floor slab thickness (3 layers)
art_bleed   = 0.4;                // slab overlaps past the recess edge so no
                                  // body-colored seam shows on the floor
bb_cx       = 79.02;              // measured import-space center
bb_cy       = 56.16;
icon_s      = icon_w / 126.43;    // measured import-space width
// soma (orange dot) center — MEASURED by importing the isolated soma path
// through the same pipeline (import-space center 40.43, 55.56 → offset from
// icon center dx -38.59, dy -0.60). The plate prints face-up so the art is
// NOT mirrored: the offset applies with its own sign.
soma_x      = icon_cx - 38.59 * icon_s;
soma_y      = -0.60 * icon_s;
art_fat     = 0.25;               // stroke fattening: thinnest dendrites become
                                  // ~2mm = 4-5 extrusion lines
wordmark    = "PRE-Sync";
word_font   = "Futura:style=Bold";   // geometric, heavy — matches the logo's circles
word_x      = 50;                 // centered in the clear zone right of icon
word_size   = 7;

// ---- Ground/tether screw (right end wall, dead center) ----------------------
// IDEAL 774044R-style 10-32 thread-forming grounding screw (green): tether
// ring terminal under the head OUTSIDE, screw self-taps the wall — line the
// interior with copper foil over this area and the threads contact it on the
// way through = the shield's single ground point. No nut needed.
gnd_d      = 4.3;   // 10-32 thread-forming bite in 3mm PLA (major dia 4.8)
gnd_y      = 0;
gnd_zp     = 18.5;  // mid-height of the assembled box (lid on)
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

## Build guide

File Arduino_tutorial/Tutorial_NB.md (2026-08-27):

## 1. Install the toolchain (macOS)

Open a terminal and run:

```bash
# Install the Arduino command-line tool
brew install arduino-cli

# Download the board index
arduino-cli core update-index

# Install the compiler + tools for standard AVR boards (Uno, Leonardo, Micro, ...)
arduino-cli core install arduino:avr
```

Verify it works:

```bash
arduino-cli version
```

### VS Code setup

VS Code is just your editor here — all compiling/uploading happens in the terminal (use VS Code's built-in terminal: ``Ctrl+` ``).

- Install the **C/C++** extension (Microsoft) so `.ino` files get syntax highlighting and autocomplete.
- Optional: the **Arduino Community Edition** extension adds a serial monitor button, but you don't need it — everything below uses the terminal.

## 2. Know your board

Every board has an **FQBN** (Fully Qualified Board Name) that tells the compiler what chip it's building for. Common ones:

| Board | FQBN | Upload quirk |
|---|---|---|
| Arduino Uno | `arduino:avr:uno` | none, just upload |
| Arduino Leonardo | `arduino:avr:leonardo` | may need a reset double-tap, see section 5 |
| Pro Micro (ATmega32U4) | `arduino:avr:micro` | same, but no reset button (short RST to GND instead) |

Plug the board in over USB and find its port:

```bash
arduino-cli board list
```

You'll see something like `/dev/cu.usbmodem14101` (macOS) or `COM3` (Windows). That port name goes into every upload command below.

## 3. Project layout

`arduino-cli` requires the sketch folder name to match the `.ino` filename:

```
fsr_reader/
└── fsr_reader.ino
```

That's the whole project. Create it anywhere, open the folder in VS Code, and edit the `.ino` file.

---

## 4. The example: read a force sensing resistor

An FSR is a flat pad whose electrical resistance drops as you press on it (~1 MΩ untouched → a few kΩ pressed hard). The Arduino can't measure resistance directly, but it can measure **voltage** — so we build a **voltage divider**:

```
  5V ----[ FSR ]----+----[ 10 kΩ resistor ]---- GND
                    |
                    A0  (analog input)
```

**Wiring steps (3 wires + 1 resistor on a breadboard):**

1. One leg of the FSR → **5V** pin (labeled **VCC** on the Pro Micro)
2. Other leg of the FSR → a breadboard row; from that same row, a **10 kΩ resistor** → **GND** pin
3. A wire from that middle junction → **A0**

When you press the FSR, its resistance drops, so more of the 5V appears at A0. `analogRead(A0)` converts that voltage into a number: **0** (0V, no press) to **1023** (5V, hard press).

The complete sketch is in [`fsr_reader/fsr_reader.ino`](fsr_reader/fsr_reader.ino). The core of it:

```cpp
const int FSR_PIN = A0;

void setup() {
  // 115200 is the baud rate: how many bits per second flow over the
  // serial connection between the board and your computer. Both sides
  // have to agree on it, which is why the sketch says Serial.begin(115200)
  // and the monitor command says --config baudrate=115200. If they
  // disagree, the bytes get sliced at the wrong intervals and you
  // see garbage.
  Serial.begin(115200);
}

void loop() {
  int raw = analogRead(FSR_PIN);           // 0–1023
  float voltage = raw * (5.0 / 1023.0);    // convert to volts

  Serial.print(raw);
  Serial.print('\t');
  Serial.println(voltage, 2);

  delay(100);                    // 10 readings per second
}
```

---

## 5. Compile and upload from the terminal

From the directory *containing* the `fsr_reader` folder:

**Compile** (checks your code and builds the binary — catch errors here first):

```bash
arduino-cli compile --fqbn arduino:avr:micro fsr_reader
```

**Upload** (replace the port with what `arduino-cli board list` showed you):

```bash
arduino-cli upload --fqbn arduino:avr:micro -p /dev/cu.usbmodem14101 fsr_reader
```

These use the Pro Micro FQBN. Substitute `arduino:avr:uno`, `arduino:avr:leonardo`, etc. if you're on a different board.

> **Leonardo / Pro Micro quirk:** these boards have to be in "bootloader mode" to accept an upload. The upload command normally handles this for you (it pokes the port at 1200 baud, which reboots the board), so most of the time uploads just work. If an upload fails, or a buggy sketch has taken down the USB connection, you have to force it manually with a double-tap reset. On a Leonardo that means double-tapping the reset button. The Pro Micro has no reset button, so instead you briefly short the RST pin to GND twice in quick succession with a jumper wire. Either way the board then sits in bootloader mode for about 8 seconds, usually under a *different* port name, so run `arduino-cli board list` again right after and upload to whatever port it shows. An Uno has none of this, you just run upload.

**Typical loop while developing:** edit in VS Code → `compile` → fix errors → `upload` → watch serial output. Re-upload any time; the new program replaces the old one.

---

## 6. Watch the data: serial monitor

The board prints readings over USB. Open the monitor from the terminal (the baud rate must match the `Serial.begin()` value in the sketch):

```bash
arduino-cli monitor -p /dev/cu.usbmodem14101 --config baudrate=115200
```

Press the FSR and you'll see the numbers climb:

```
raw (0-1023)	voltage (V)
12	0.06
14	0.07
389	1.90      <- light press
801	3.91      <- firm press
```

`Ctrl+C` exits the monitor. **Note:** the serial port can only be held by one program at a time — close the monitor before uploading, or the upload will fail with a "port busy" error.

---

## 7. Adapting this to other sensors

The pattern above covers a huge range of lab sensors:

- **Anything resistive** (photoresistors, thermistors, flex sensors, other FSRs): same voltage-divider circuit, same `analogRead()`. Only the fixed resistor value and the interpretation of the number change.
- **Anything that outputs a voltage** (many accelerometers, EMG boards, potentiometers): wire its output straight to A0–A5 and `analogRead()` it — no divider needed, as long as its output stays within 0–5V.
- **Switches / buttons / TTL triggers**: use a digital pin with `digitalRead()`.
- **Smart sensors (I2C/SPI)** — IMUs, precision temperature, etc.: these need a library. Install with e.g. `arduino-cli lib search mpu6050` then `arduino-cli lib install "<library name>"`, and follow the library's example.

To log sensor data to a file for analysis, print comma-separated values in the sketch and capture the serial stream, e.g.:

```bash
arduino-cli monitor -p /dev/cu.usbmodem14101 --config baudrate=115200 | tee data.csv
```

---

## 8. Generating signals: pseudo-random pulses on two channels

So far we've read a pin. This example drives pins instead: it flips them HIGH and LOW at pseudo-random intervals, same idea as our sync pulse generator boxes, but stripped down to show how you pick which signal goes to which pin. It runs two channels at different speeds so you can see they're independent:

- channel A on pin 2, fast pulses (25–150 ms per state)
- channel B on pin 3, slow pulses (200–1000 ms per state)

To see a channel, wire an LED (with a ~220 Ω resistor) from its pin to GND, or clip a scope probe across pin and GND. If you want a no-wiring demo, temporarily set a channel's pin to 17: that's the Pro Micro's onboard RX LED, and it will blink the pattern (inverted, since that LED lights when the pin is LOW — fine for watching). On a Leonardo or Uno, pin 13 is the onboard LED.

Full sketch: [`dual_pulse/dual_pulse.ino`](dual_pulse/dual_pulse.ino).

### Picking which pin gets which signal

There is no special "channel" hardware. A channel is just a pin the code decides to write to. The sketch keeps that mapping in one table:

```cpp
struct Channel {
  const char* name;         // label used in serial output
  int pin;                  // which board pin this channel drives
  unsigned long minMs;      // shortest time in one state (ms)
  unsigned long maxMs;      // longest time in one state (ms)
  uint32_t prng;            // PRNG seed (nonzero)
  bool state;
  unsigned long nextToggle;
};

Channel channels[] = {
  // name  pin  min   max   seed
  { "A",   2,   25,   150,  42   },
  { "B",   3,   200,  1000, 1337 },
};
```

That table is the whole routing story. Want channel A on pin 7 instead? Change the 2 to a 7 and re-upload. Want a third channel on pin 5? Add a row. Each row carries its own timing range and its own random seed, which is what lets every channel run at its own speed with its own (reproducible) pattern. On the Pro Micro the usable pins are 0–10, 14–16, and A0–A3; there is no pin 11, 12, or 13.

Physically, "channel A" is then just pin 2 + GND: hook a scope probe, BNC, or an LED (with a ~220 Ω resistor to GND) across those two points.

### Why there's no delay() in this sketch

The obvious way to blink a pin is `delay(100)` between flips, but delay() puts the whole chip to sleep — while it waits, nothing else can happen, so two channels at different speeds would be impossible. Instead the sketch keeps a "when do I flip next" timestamp for each channel and checks the clock on every pass through loop():

```cpp
void loop() {
  unsigned long now = millis();   // ms since power-on
  for (int i = 0; i < NUM_CHANNELS; i++) {
    Channel &ch = channels[i];
    if (now >= ch.nextToggle) {                 // is this channel due?
      ch.state = !ch.state;
      digitalWrite(ch.pin, ch.state);           // flip the pin
      ch.nextToggle = now + randomDuration(ch); // schedule the next flip
    }
  }
}
```

loop() runs thousands of times per second, so each channel gets flipped within a fraction of a millisecond of its scheduled time, and a slow channel never blocks a fast one. This millis() pattern is the trick for doing several things at once on a microcontroller — the sync pulse generator uses the same one.

### Where the "random" comes from

Each channel runs a tiny pseudo-random number generator (PRNG). Feed the result back in and you get a stream of random-looking numbers. The whole thing is three lines:

```cpp
uint32_t prngNext(uint32_t &state) {
  state ^= state << 13;   // xorshift32: shift the bits, XOR them
  state ^= state >> 17;   //   back in, three times over
  state ^= state << 5;
  return state;
}
```

This part is cool. What is happening above is we are taking a 32 bit value (state), represented in binary. State might equal 10110000...n32 to start. We perform 3 XOR operations. Each one compares state to state shifted 13 bits to the left and those that fall off are replaced by 0's. State becomes a new binary value, where each bit that matched between the two becomes 0, and each that didn't become 1. You then do this shifting 17 to the right and then 5 to the left. Those specific shift values (13, 17, 5) are unique in that they allow you to shift through all 4,294,967,295 nonzero 32-bit values before repeating. 

The starting number (state) is the seed (the 42 and 1337 in the channel table). Because the scrambling is deterministic, the same seed always produces the exact same sequence of numbers, and therefore the exact same pulse pattern, every power cycle. That's what our sync boxes are doing and analysis code can regenerate the expected pattern from just the seed. Change the seed to get a different pattern; keep it to get the same one. We keep it set so that we could generate the pattern in Matlab or Python, if need be.

Each PRNG output is then squashed into the channel's min–max range, in 5 ms steps:

```cpp
unsigned long randomDuration(Channel &ch) {
  if (ch.minMs >= ch.maxMs) return ch.minMs;
  uint32_t steps = (ch.maxMs - ch.minMs) / 5 + 1;      // how many 5 ms slots fit
  return ch.minMs + (prngNext(ch.prng) % steps) * 5;   // pick one of them
}
```

**One caution: the seed must not be 0 — xorshift scrambles 0 into 0 forever, so a zero-seeded channel would never look random.**

### Upload and watch it

```bash
arduino-cli compile --fqbn arduino:avr:micro dual_pulse
arduino-cli upload --fqbn arduino:avr:micro -p /dev/cu.usbmodem101 dual_pulse
arduino-cli monitor -p /dev/cu.usbmodem101 --config baudrate=115200
```

The monitor narrates both channels:

```
Dual-channel pulse generator running
  Channel A -> pin 2, 25-150 ms
  Channel B -> pin 3, 200-1000 ms
A HIGH for 65 ms
A LOW  for 130 ms
B HIGH for 850 ms
A HIGH for 40 ms
...
```

Notice A toggles several times while B holds one state. Two speeds, two pins, one program.

### Running it without a computer

The uploaded program lives in the chip's flash memory and runs any time the board has power — the serial printing just goes nowhere if nothing is listening. Ways to power a deployed board:

- **USB**: any USB charger or power bank.
- **RAW pin**: unregulated DC in, roughly 5.5–12V. A 9V center-positive barrel adapter wired to RAW + GND works well (this is how our sync boxes are powered). The onboard regulator drops it to 5V.
- **VCC pin**: regulated 5V only. This bypasses the regulator, so never feed 9V here.

When reprogramming a box, unplug the barrel adapter and connect USB alone. Standard Pro Micros tolerate both at once, but not every clone includes the protection diode that makes that safe.

---

## 9. What if you have an ESP32 or another board?

The workflow (VS Code + `arduino-cli` + terminal) and the code API (`setup()`, `loop()`, `analogRead()`, `Serial`) are the same on virtually every hobby microcontroller. What changes:

**ESP32** — needs its own core (one-time setup), since it's not made by Arduino:

```bash
arduino-cli config init
arduino-cli config add board_manager.additional_urls https://espressif.github.io/arduino-esp32/package_esp32_index.json
arduino-cli core update-index
arduino-cli core install esp32:esp32
```

Then compile/upload with `--fqbn esp32:esp32:esp32` (run `arduino-cli board listall esp32` to find the exact FQBN for your specific board). No reset-button dance — uploads just work on most dev boards (a few require holding the **BOOT** button as the upload starts).

**Mac note:** ESP32 dev boards show up as `/dev/cu.usbserial-*`, `/dev/cu.wchusbserial*`, or `/dev/cu.SLAB_USBtoUART` rather than `usbmodem`. Recent macOS versions include the needed USB drivers; if `arduino-cli board list` shows nothing after plugging in, the board's USB chip (usually CH340 or CP210x) needs its driver installed — search "CH340 macOS driver" or "CP210x macOS driver". Also make sure you're using a **data** USB cable, not a charge-only one (the most common "board not detected" cause).

Two differences that **matter for the FSR circuit**:

1. **ESP32 is a 3.3V chip.** Power the voltage divider from the **3V3 pin, not 5V** — 5V on an analog pin can damage it.
2. **The ADC is 12-bit**: `analogRead()` returns **0–4095**, so the conversion is `raw * (3.3 / 4095.0)` and any thresholds scale up ~4×. Use a GPIO on ADC1 (**GPIO 32–39**) as the input — most ESP32 boards have no `A0` alias, and ADC2 pins stop working when WiFi is active.

**Other boards** (Nano 33, Raspberry Pi Pico, Teensy, …): same pattern — install that board's core, use its FQBN, and check its logic voltage. Classic AVR boards (Uno, Nano, Mega) are 5V and covered by `arduino:avr` already; almost everything newer is 3.3V.

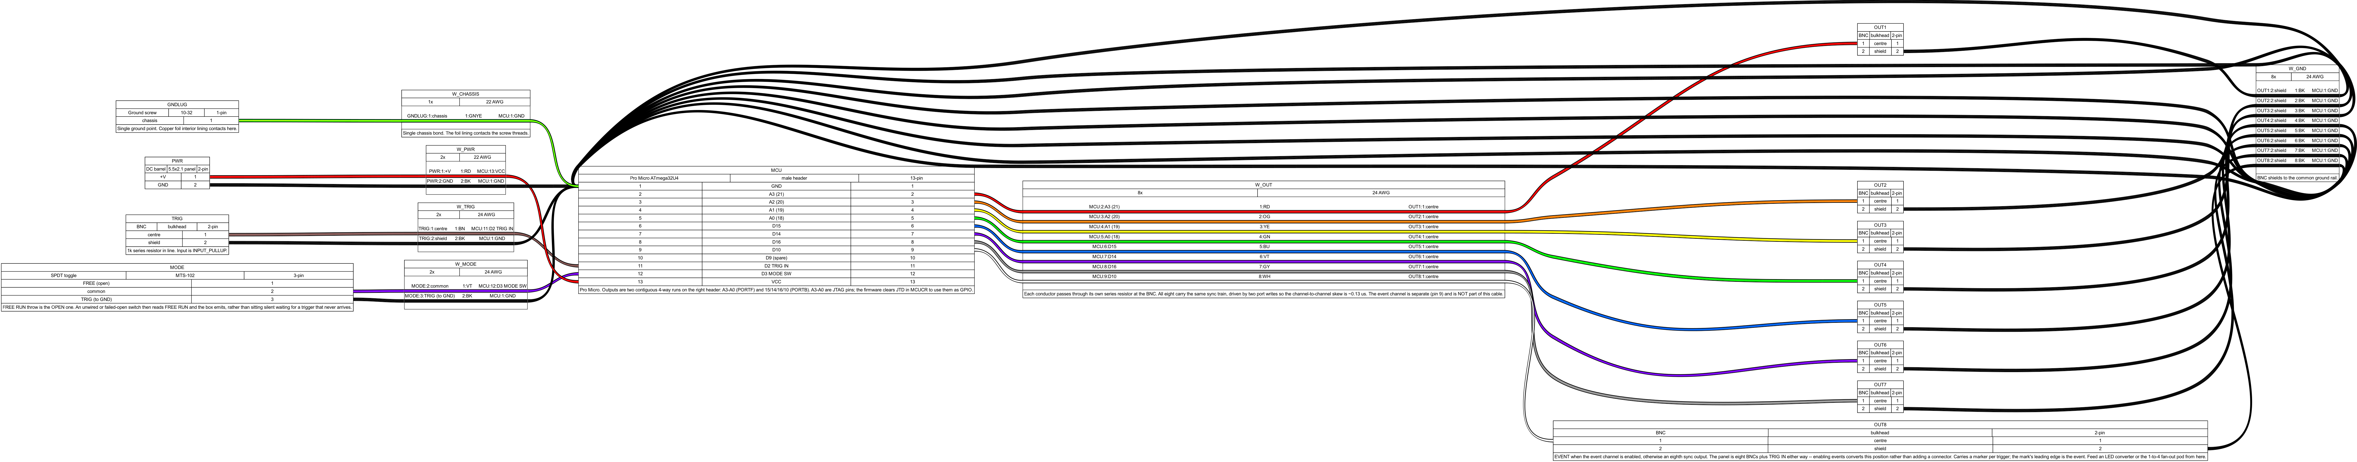
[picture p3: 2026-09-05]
docs/wiring/presync-harness.png

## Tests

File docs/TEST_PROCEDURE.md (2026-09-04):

# PRE-Sync — Acceptance test procedure

What a built unit must demonstrate before it is used for data collection, and
what fills the *TBM* entries in the datasheet.

Record results in `docs/test-results/<serial>-<date>.md`. A unit with an
incomplete sheet is not qualified.

## 1. Visual and continuity

- [ ] All connectors seated; no strain on solder joints.
- [ ] Copper foil lining bonded at the ground screw, **one point only** — a
      second bond makes a ground loop.
- [ ] Continuity: each BNC shield to chassis ground.
- [ ] Isolation: each BNC centre to every other centre, open circuit.

## 2. Power-on

- [ ] Draws power without excessive current.
- [ ] USB enumerates as a serial device.
- [ ] `config` returns the running configuration.
- [ ] Onboard LED (Leonardo pin 13) mirrors the signal.

## 3. Output waveform — oscilloscope

For each of the eight panel outputs:

- [ ] Amplitude 5 V ±0.25 V, unloaded.
- [ ] Amplitude under a realistic recorder load. **Record the value.**
- [ ] Rise time, 10–90%. **Record.**
- [ ] Fall time, 90–10%. **Record.**
- [ ] No ringing or overshoot beyond 10%.

Then, across channels:

- [ ] Channel-to-channel skew, all eight simultaneously. **Record the worst
      pair.** This bounds the accuracy of anything aligned between two devices
      fed from different outputs.

## 4. Independent driver claim

The datasheet states that loading one channel does not disturb the others.
This is a design claim and must be demonstrated, not asserted:

- [ ] Short one output to ground. Verify the other seven are unaffected in
      amplitude and timing.
- [ ] Load one output heavily (e.g. 100 Ω). Same check.
- [ ] Confirm the shorted channel recovers when the fault is removed.

## 5. Generator clock accuracy

Every alignment the device supports is bounded by this number.

- [ ] Measure actual pulse durations against a calibrated reference over at
      least 10 minutes.
- [ ] Compute the mean error in ppm. **Record.**
- [ ] Confirm durations land on the 5 ms quantum.

## 6. Timecode

- [ ] Enable frames (`tc on`). Confirm one frame per interval.
- [ ] Decode with `utils/python/timecode.py`; checksums pass.
- [ ] Verify the frame's first edge marks exactly `elapsed` seconds.
- [ ] Power-cycle; confirm the run ID incremented and persists.

## 7. Trigger modes

For each of `start`, `toggle`, `gate`:

- [ ] Behaves as specified in `docs/INTERFACE.md` §5.
- [ ] With TRIG unconnected, no false trigger over 10 minutes.
- [ ] Lead-in marker (`mark on`): one clean pulse, correct pause, run clock
      starting at the marker's leading edge.

## 8. Mode switch fail-safe

- [ ] Disconnect the mode switch entirely. **The box must free-run**, not sit
      silent. This is the single most important failure behaviour in the
      device.

## 9. End-to-end

- [ ] Record the signal on two or more systems at different sample rates, at
      least one edge-only.
- [ ] Include a FREE→TRIG change so two run IDs appear in one session.
- [ ] Analyse with `python3 -m presync run`. Confirm every stream locates and
      reports drift, jitter and capture.
- [ ] Multi-hour run: confirm rate estimation holds where it matters.

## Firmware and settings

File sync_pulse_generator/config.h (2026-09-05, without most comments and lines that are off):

#define CONFIG_H
#define FW_VERSION        "2.0.0"
#define PROTOCOL_VERSION  4
#define FW_DATE           __DATE__
  #define HW_VARIANT      "leonardo"
#define TIMER_PRESCALE      8      // 16 MHz / 8 -> 0.5 us per tick
#define TICKS_PER_US        2      // ...so 2 ticks per microsecond
  #define NUM_OUTPUT_PINS 20
#define EVENT_CHANNEL_ENABLED 1
  #define PANEL_PINS      {0, 1, 4, 6, 8, 10, 11, 12}
  #define EVENT_CHANNEL_PIN 12       // BNC 8, the last panel position
  #define EVENT_PORTB_MASK  0x00     // pin 12 is PORTD, not PORTB
  #define OUT_PORTF_MASK    0x00
  #define OUT_PORTB_MASK    0xD0
  #if EVENT_CHANNEL_ENABLED
    #define OUT_PORTD_MASK  0x9C     // 0,1,4,6 -- BNC 8 carries events
  #else
    #define OUT_PORTD_MASK  0xDC     // 0,1,4,6,12 -- all eight are sync
  #endif
  #define PANEL_LED_PIN   16
  #define PANEL_LED_MASK  0x04     // PB2
#define DEFAULT_MIN_HIGH_MS  50
#define DEFAULT_MAX_HIGH_MS  500
#define DEFAULT_MIN_LOW_MS   50
#define DEFAULT_MAX_LOW_MS   500
#define DURATION_STEP_US  250
#define DURATION_STEP_MS  (DURATION_STEP_US / 1000.0)
#define DEFAULT_PRNG_SEED    42
#define DEFAULT_TC_ENABLED    1     // 1 = frames on, 0 = pure pseudo-random
#define DEFAULT_TC_INTERVAL_S 10    // seconds between frames (min 2)
#define TC_LEADIN_MS          20    // forced LOW before each frame tick
#define TC_PULSE_MS           5     // frame pulse width (constant)
#define TC_PREAMBLE_GAP_MS    10    // gap inside the 3-pulse preamble
#define TC_GAP_ZERO_MS        15    // bit gap meaning 0
#define TC_GAP_ONE_MS         25    // bit gap meaning 1
#define TRIG_FEATURE        1
#define TRIG_IN_PIN         2
#define MODE_SWITCH_PIN     3
#define MODE_FREE_IS_LOW    0   // open throw = FREE RUN (see above)
#define TRIG_ARM_LOW_MS     20
#define EEPROM_RUNID_ADDR   64
#define TRIG_MODE_EDGE_START   0
#define TRIG_MODE_EDGE_TOGGLE  1
#define TRIG_MODE_LEVEL_GATE   2
#define DEFAULT_TRIG_MODE      TRIG_MODE_EDGE_START
#define DEFAULT_LEADIN_PULSE_ENABLED 0    // 1 = emit the marker pulse
#define DEFAULT_LEADIN_PULSE_MS      50   // marker pulse width
#define DEFAULT_LEADIN_PAUSE_MS      500  // LOW hold before the train starts
#define EVENT_MARK_MS         200  // the event itself; leading edge = timestamp
#define EVENT_GAP_MS          50   // between symbols
#define EVENT_BIT0_MS         50   // short symbol = 0
#define EVENT_BIT1_MS         100  // long symbol  = 1
#define EVENT_COUNTER_BITS    8    // 0-255, wraps
#define EEPROM_MAGIC  0xA9

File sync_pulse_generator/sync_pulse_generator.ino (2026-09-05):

/*
 * Pseudo-Random Square Wave Sync Pulse Generator
 * Nathan Baune
 *
 * Outputs a pseudo-random square wave on configurable pins.
 * The high and low durations are randomized within configurable
 * min/max ranges (in milliseconds). The pseudo-random pattern
 * has a sharp autocorrelation peak, making it ideal for
 * cross-correlation-based temporal alignment of multi-device
 * recordings (Vicon, EEG, etc.).
 *
 * Configuration:
 *   - Edit config.h for compile-time defaults
 *   - Use Serial commands at runtime to adjust
 *   - 'save' persists current settings to EEPROM
 *   - Settings survive power cycles after saving
 *
 * Voltage: 5V HIGH / 0V LOW (hardware fixed by ATmega32U4)
 *
 * Supported boards (both use ATmega32U4):
 *   - Arduino Leonardo          -- FQBN: arduino:avr:leonardo  (20 pins)
 *   - Pro Micro ATmega32U4 5V  -- FQBN: arduino:avr:micro      (18 pins)
 *     Define BOARD_PRO_MICRO in config.h or via compiler flag to select
 *     the Pro Micro pin layout.
 */

#include <EEPROM.h>
#include "config.h"

void stopEmitting();
void startEmitting();

// ---- Pin setup ----
// Pro Micro (BOARD_PRO_MICRO): 18 pins — 0-10, 14-16, A0-A3
// Leonardo (default):          20 pins — 0-13, A0-A5
#ifdef BOARD_PRO_MICRO
const int OUTPUT_PINS[] = {0, 1, 2, 3, 4, 5, 6, 7, 8, 9, 10, 14, 15, 16, A0, A1, A2, A3};
#else
const int OUTPUT_PINS[] = {0, 1, 2, 3, 4, 5, 6, 7, 8, 9, 10, 11, 12, 13, A0, A1, A2, A3, A4, A5};
#endif
const int NUM_PINS = NUM_OUTPUT_PINS;

#if TRIG_FEATURE
bool isReservedPin(int p) {
  if (p == TRIG_IN_PIN || p == MODE_SWITCH_PIN) return true;
#if EVENT_CHANNEL_ENABLED
  // The event channel is driven independently, so it must not be swept along
  // with the train by setOutput().
  if (p == EVENT_CHANNEL_PIN) return true;
#endif
  return false;
}
#else
bool isReservedPin(int p) {
  (void)p;
#if EVENT_CHANNEL_ENABLED
  if (p == EVENT_CHANNEL_PIN) return true;
#endif
  return false;
}
#endif

// ---- Runtime settings (loaded from EEPROM or config.h defaults) ----
unsigned long minHighMs;
unsigned long maxHighMs;
unsigned long minLowMs;
unsigned long maxLowMs;
unsigned long prngSeed;
bool tcEnabled;
unsigned long tcIntervalS;
uint8_t  trigMode_cfg;          // TRIG_MODE_* — what TRIG IN does
bool     leadinPulseEnabled;    // emit a marker pulse on trigger
unsigned long leadinPulseMs;    // its width
unsigned long leadinPauseMs;    // LOW hold after it, before the train

// ---- State ----
bool outputState = LOW;
unsigned long nextToggleTime = 0;
bool running = true;

// Timecode frame state. A frame is 55 pulses / 54 gaps = 109 alternating
// segments (even = pulse HIGH, odd = gap LOW). Segments 1,3 are preamble
// gaps; odd segments 5..107 carry the 52 payload bits MSB-first.
enum RunMode { MODE_PR, MODE_LEADIN, MODE_FRAME, MODE_MARK, MODE_MARKPAUSE };
RunMode mode = MODE_PR;
bool leadinPending = false;   // current PR segment was clamped at the lead-in start
uint8_t  frameSeg = 0;
uint64_t framePayload = 0;          // 52 bits: runId<<36 | elapsed<<4 | cksum
uint16_t runId = 0;                 // EEPROM boot counter, ++ per PRNG start
unsigned long runStartMs = 0;       // when the PRNG (re)started
unsigned long nextFrameDueMs = 0;

// ---- EEPROM layout ----
// Byte 0: magic, Bytes 1-20: settings
struct EepromData {
  uint8_t magic;
  uint32_t minHigh;
  uint32_t maxHigh;
  uint32_t minLow;
  uint32_t maxLow;
  uint32_t seed;
  uint8_t  tcEnabled;
  uint32_t tcIntervalS;
  uint8_t  trigMode;
  uint8_t  leadinEnabled;
  uint32_t leadinPulseMs;
  uint32_t leadinPauseMs;
};

void loadDefaults() {
  minHighMs   = DEFAULT_MIN_HIGH_MS;
  maxHighMs   = DEFAULT_MAX_HIGH_MS;
  minLowMs    = DEFAULT_MIN_LOW_MS;
  maxLowMs    = DEFAULT_MAX_LOW_MS;
  prngSeed    = DEFAULT_PRNG_SEED;
  tcEnabled   = DEFAULT_TC_ENABLED;
  tcIntervalS = DEFAULT_TC_INTERVAL_S;
  trigMode_cfg       = DEFAULT_TRIG_MODE;
  leadinPulseEnabled = DEFAULT_LEADIN_PULSE_ENABLED;
  leadinPulseMs      = DEFAULT_LEADIN_PULSE_MS;
  leadinPauseMs      = DEFAULT_LEADIN_PAUSE_MS;
}

bool loadFromEeprom() {
  EepromData data;
  EEPROM.get(0, data);
  if (data.magic != EEPROM_MAGIC) return false;
  minHighMs   = data.minHigh;
  maxHighMs   = data.maxHigh;
  minLowMs    = data.minLow;
  maxLowMs    = data.maxLow;
  prngSeed    = data.seed;
  tcEnabled   = data.tcEnabled != 0;
  tcIntervalS = data.tcIntervalS;
  trigMode_cfg       = data.trigMode;
  leadinPulseEnabled = data.leadinEnabled != 0;
  leadinPulseMs      = data.leadinPulseMs;
  leadinPauseMs      = data.leadinPauseMs;
  return true;
}

void saveToEeprom() {
  EepromData data;
  data.magic       = EEPROM_MAGIC;
  data.minHigh     = minHighMs;
  data.maxHigh     = maxHighMs;
  data.minLow      = minLowMs;
  data.maxLow      = maxLowMs;
  data.seed        = prngSeed;
  data.tcEnabled   = tcEnabled ? 1 : 0;
  data.tcIntervalS = tcIntervalS;
  data.trigMode      = trigMode_cfg;
  data.leadinEnabled = leadinPulseEnabled ? 1 : 0;
  data.leadinPulseMs = leadinPulseMs;
  data.leadinPauseMs = leadinPauseMs;
  EEPROM.put(0, data);
}

// ---- PRNG (xorshift32, deterministic) ----
uint32_t prngState;

void seedPrng(uint32_t seed) {
  prngState = seed ? seed : 1;
}

uint32_t prngNext() {
  prngState ^= prngState << 13;
  prngState ^= prngState >> 17;
  prngState ^= prngState << 5;
  return prngState;
}

// Durations are computed and scheduled in MICROSECONDS. The configured
// min/max stay in ms because that is how they are set and reported.
uint32_t randomDurationUs(unsigned long minMs, unsigned long maxMs) {
  if (minMs >= maxMs) return minMs * 1000UL;
  uint32_t lo = minMs * 1000UL, hi = maxMs * 1000UL;
  uint32_t steps = (hi - lo) / DURATION_STEP_US + 1;
  return lo + (prngNext() % steps) * DURATION_STEP_US;
}

uint32_t computeNextDurationUs() {
  return (outputState == HIGH) ? randomDurationUs(minHighMs, maxHighMs)
                               : randomDurationUs(minLowMs, maxLowMs);
}

#if EVENT_CHANNEL_ENABLED
// ---- Event channel ---------------------------------------------------------
// Runs as its own non-blocking state machine so the sync train is never held
// up waiting for a marker to finish. The two are completely independent: the
// train does not know events exist, and an aborted marker cannot disturb it.
//
// Marker shape:  [200 ms MARK][gap][8 payload symbols, MSB first][gap]
// where a symbol is 50 ms for 0 and 100 ms for 1, each followed by a gap.
// The MARK's rising edge is the event timestamp.
uint8_t  eventCounter    = 0;      // wraps at 255; 0 = no events yet this run
bool     eventActive     = false;  // a marker is playing
uint8_t  eventSeg        = 0;      // 0 = mark, then 1..2N alternating gap/sym
uint8_t  eventPayload    = 0;      // the counter value being transmitted
uint32_t eventNextChange = 0;
bool     eventPinState   = LOW;

void eventPinWrite(bool st) {
  eventPinState = st;
  digitalWrite(EVENT_CHANNEL_PIN, st);
}

// Total segments after the mark: for each bit, one gap then one symbol.
static const uint8_t EVENT_SEGS = 1 + 2 * EVENT_COUNTER_BITS;

// Duration of segment `seg`. Even segments after 0 are gaps, odd are symbols.
uint16_t eventSegMs(uint8_t seg) {
  if (seg == 0) return EVENT_MARK_MS;
  if ((seg & 1) == 1) return EVENT_GAP_MS;          // gap
  uint8_t bitIndex = (seg / 2) - 1;                  // 0..N-1, MSB first
  uint8_t shift = (EVENT_COUNTER_BITS - 1) - bitIndex;
  bool one = (eventPayload >> shift) & 1;
  return one ? EVENT_BIT1_MS : EVENT_BIT0_MS;
}

// Fire a marker NOW. Called from the trigger path; the rising edge here is
// what analysis reads as the event time, so nothing may delay it — including
// a marker already in progress, which is simply cut short.
void eventFire() {
  eventCounter++;                     // first event of a run is 1
  eventPayload = eventCounter;
  eventActive = true;
  eventSeg = 0;
  eventPinWrite(HIGH);
  eventNextChange = millis() + EVENT_MARK_MS;
}

void serviceEventChannel() {
  if (!eventActive) return;
  if ((int32_t)(millis() - eventNextChange) < 0) return;
  eventSeg++;
  if (eventSeg > EVENT_SEGS) {
    eventActive = false;
    eventPinWrite(LOW);
    return;
  }
  // Gaps are LOW, symbols are HIGH.
  eventPinWrite((eventSeg & 1) ? LOW : HIGH);
  eventNextChange = millis() + eventSegMs(eventSeg);
}
#endif  // EVENT_CHANNEL_ENABLED

// ---- Output: two port writes, not eight digitalWrite() calls ---------------
// Called from the ISR, so it must be fast and it must not touch pins outside
// the masks -- other bits on these ports belong to the trigger inputs, the
// event channel and USB.
inline void writeOutputs(bool state) {
  const uint8_t d = OUT_PORTD_MASK;
  const uint8_t f = OUT_PORTF_MASK;
  const uint8_t b = OUT_PORTB_MASK | PANEL_LED_MASK;  // LED mirrors the train
  if (state) {
    if (d) PORTD |= d;
    if (f) PORTF |= f;
    PORTB |= b;
  } else {
    if (d) PORTD &= ~d;
    if (f) PORTF &= ~f;
    PORTB &= ~b;
  }
}

void setOutput(bool state) {
  outputState = state;
  writeOutputs(state);
}

// (Re)start a fresh run: re-seed, outputs LOW, new run ID.
void startNewRun() {
  startEmitting();
#if EVENT_CHANNEL_ENABLED
  // Event numbering is per-run: event 3 of run 7 is unambiguous, and a
  // counter that carried across runs would not be.
  eventCounter = 0;
  eventActive = false;
  eventPinWrite(LOW);
#endif
  seedPrng(prngSeed);
  outputState = LOW;
  setOutput(LOW);
  nextToggleTime = millis();
  resetRunClock();
  running = true;
}

// ---- Timecode frames ----
// XOR of the eight 4-bit nibbles of the payload value.
uint8_t checksum4(uint32_t v) {
  uint8_t c = 0;
  for (uint8_t i = 0; i < 8; i++) { c ^= v & 0xF; v >>= 4; }
  return c;
}

// Reset the run clock + frame schedule (called wherever the PRNG restarts).
// Each call is a new RUN: the persistent counter increments so (runId,
// elapsed) stays globally unique across restarts and power cycles.
void resetRunClock() {
  uint16_t counter;
  EEPROM.get(EEPROM_RUNID_ADDR, counter);
  if (counter == 0xFFFF) counter = 0;   // fresh EEPROM
  counter++;
  EEPROM.put(EEPROM_RUNID_ADDR, counter);
  runId = counter;
  runStartMs = millis();
  nextFrameDueMs = runStartMs + tcIntervalS * 1000UL;
  mode = MODE_PR;
  leadinPending = false;
}

// Begin emitting a frame: first preamble pulse goes HIGH now — ON the tick,
// so the encoded elapsed time is exact by construction.
void startFrame() {
  uint32_t elapsedS = (nextFrameDueMs - runStartMs) / 1000UL;
  uint8_t chk = checksum4(elapsedS) ^ checksum4(runId);
  framePayload = ((uint64_t)runId << 36) | ((uint64_t)elapsedS << 4) | chk;
  frameSeg = 0;
  mode = MODE_FRAME;
  setOutput(HIGH);
  nextToggleTime = millis() + TC_PULSE_MS;
}

// Duration of frame segment `seg` (0..108). Even = pulse, odd = gap.
unsigned long frameSegmentDuration(uint8_t seg) {
  if (seg % 2 == 0) return TC_PULSE_MS;
  if (seg < 4) return TC_PREAMBLE_GAP_MS;          // gaps 1, 3
  uint8_t bitIdx = (seg - 5) / 2;                  // odd segs 5..107 -> 0..51
  bool bit = (framePayload >> (51 - bitIdx)) & 1;
  return bit ? TC_GAP_ONE_MS : TC_GAP_ZERO_MS;
}

// Hold LOW until the frame tick; the frame's first pulse then rises ON it.
void enterLeadIn() {
  outputState = LOW;
  setOutput(LOW);
  mode = MODE_LEADIN;
  nextToggleTime = nextFrameDueMs;
}

// Schedule the pseudo-random segment for the state just set. The PRNG draw
// ALWAYS happens (reproducibility); the segment is clamped to end at the
// lead-in start if it would cross it.
void schedulePrSegment() {
  // The draw ALWAYS happens, even if the segment is then clamped: the PRNG
  // sequence must not depend on where frames fall, or the waveform stops
  // being reproducible from (seed, config).
  uint32_t dUs = computeNextDurationUs();
  unsigned long now = millis();
  if (tcEnabled) {
    long remaining = (long)(nextFrameDueMs - TC_LEADIN_MS - now);
    if (remaining <= 0) { enterLeadIn(); return; }          // ran late
    if ((long)(dUs / 1000UL) > remaining) {
      nextToggleTime = now + remaining;
      leadinPending = true;
      scheduleEdgeUs((uint32_t)remaining * 1000UL);
      return;
    }
  }
  nextToggleTime = now + (dUs / 1000UL);
  scheduleEdgeUs(dUs);
}

// Next frame tick strictly ahead of now (+lead-in) on the run's interval
// grid — used when timecode is switched on or the interval changes mid-run,
// so a stack of overdue frames is never emitted back-to-back.
void scheduleNextFrame() {
  unsigned long period = tcIntervalS * 1000UL;
  unsigned long elapsed = millis() - runStartMs + TC_LEADIN_MS;
  nextFrameDueMs = runStartMs + (elapsed / period + 1) * period;
  leadinPending = false;
}

void printConfig() {
  Serial.println(F("=== Sync Pulse Generator Config ==="));
  Serial.print(F("  Firmware: ")); Serial.print(F(FW_VERSION));
  Serial.print(F("  built ")); Serial.println(F(FW_DATE));
  Serial.print(F("  Protocol: ")); Serial.print(PROTOCOL_VERSION);
  Serial.println(F("   (the signal on the wire; decoders match on this)"));
  Serial.print(F("  Hardware: ")); Serial.print(F(HW_VARIANT));
#if EVENT_CHANNEL_ENABLED
  Serial.print(F("+event"));
#endif
#if !TRIG_FEATURE
  Serial.print(F(" freerun-build"));
#endif
  Serial.println();
  Serial.print(F("  Seed:     ")); Serial.println(prngSeed);
  Serial.print(F("  High ms:  ")); Serial.print(minHighMs);
  Serial.print(F(" - "));          Serial.println(maxHighMs);
  Serial.print(F("  Low ms:   ")); Serial.print(minLowMs);
  Serial.print(F(" - "));          Serial.println(maxLowMs);
  Serial.print(F("  Voltage:  5V HIGH / 0V LOW"));
  Serial.println();
  Serial.print(F("  Run ID:   ")); Serial.println(runId);
  Serial.print(F("  Timecode: "));
  if (tcEnabled) {
    Serial.print(F("ON, frame every "));
    Serial.print(tcIntervalS);
    Serial.println(F(" s"));
  } else {
    Serial.println(F("OFF (pure pseudo-random)"));
  }
  // Only the pins actually carrying the train. Printing the raw array listed
  // the reserved trigger pins and the event channel as sync outputs, which is
  // exactly the sort of thing someone wires a BNC to and then cannot explain.
  {
    const uint8_t panel[] = PANEL_PINS;
    const uint8_t n = sizeof(panel);
    Serial.print(F("  BNC 1-"));
    Serial.print(n);
    Serial.print(F(":  "));
    for (uint8_t i = 0; i < n; i++) {
      if (i) Serial.print(F(", "));
      Serial.print(panel[i]);
#if EVENT_CHANNEL_ENABLED
      if (panel[i] == EVENT_CHANNEL_PIN) Serial.print(F("=EVENT"));
#endif
    }
    Serial.println();
#if EVENT_CHANNEL_ENABLED
    Serial.print(F("  Sync:      ")); Serial.print(n - 1);
    Serial.println(F(" channels; BNC 8 carries events"));
#else
    Serial.print(F("  Sync:      ")); Serial.print(n);
    Serial.println(F(" channels; event channel off"));
#endif
    Serial.println(F("             2 port writes, ~0.13 us sweep"));
  }
  Serial.print(F("  Panel LED: ")); Serial.println(PANEL_LED_PIN);
  Serial.print(F("  Quantum:   ")); Serial.print(DURATION_STEP_US);
  Serial.println(F(" us, Timer3 compare-match (~1 us ISR latency)"));
#if EVENT_CHANNEL_ENABLED
#endif
#if TRIG_FEATURE
  Serial.print(F("  Reserved:  "));
  Serial.print(TRIG_IN_PIN); Serial.print(F(" TRIG IN, "));
  Serial.print(MODE_SWITCH_PIN); Serial.println(F(" MODE SW"));
#endif
#if TRIG_FEATURE
  Serial.print(F("  Mode:     "));
  Serial.println(digitalRead(MODE_SWITCH_PIN) == LOW
                 ? (MODE_FREE_IS_LOW ? F("FREE RUN") : F("TRIG RUN"))
                 : (MODE_FREE_IS_LOW ? F("TRIG RUN") : F("FREE RUN")));
#endif
  Serial.print(F("  TrigMode: "));
  Serial.println(trigMode_cfg == TRIG_MODE_EDGE_START  ? F("start")
               : trigMode_cfg == TRIG_MODE_EDGE_TOGGLE ? F("toggle")
                                                       : F("gate"));
  Serial.print(F("  Marker:   "));
  if (leadinPulseEnabled) {
    Serial.print(F("ON, ")); Serial.print(leadinPulseMs);
    Serial.print(F(" ms pulse + ")); Serial.print(leadinPauseMs);
    Serial.println(F(" ms pause"));
  } else {
    Serial.println(F("OFF"));
  }
  Serial.print(F("  Running:  ")); Serial.println(running ? "YES" : "NO");
  Serial.println(F("==================================="));
}

void printHelp() {
  Serial.println(F("Commands:"));
  Serial.println(F("  high <min> <max>  - Set high duration range (ms)"));
  Serial.println(F("  low <min> <max>   - Set low duration range (ms)"));
  Serial.println(F("  seed <value>      - Set PRNG seed & restart"));
  Serial.println(F("  tc on|off         - Timecode frames on/off"));
  Serial.println(F("  tcint <seconds>   - Seconds between timecode frames"));
  Serial.println(F("  trigmode <m>      - start|toggle|gate"));
  Serial.println(F("  mark on|off       - lead-in marker pulse on trigger"));
  Serial.println(F("  markms <p> <g>    - marker pulse ms, then pause ms"));
  Serial.println(F("  save              - Save settings to EEPROM"));
  Serial.println(F("  reset             - Reset to config.h defaults"));
  Serial.println(F("  start             - Start output"));
  Serial.println(F("  stop              - Stop output (pins LOW)"));
  Serial.println(F("  restart           - Re-seed PRNG & restart"));
  Serial.println(F("  config            - Show current config"));
  Serial.println(F("  help              - Show this help"));
}

// ---- Serial command parsing ----
char cmdBuffer[64];
int cmdPos = 0;
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
void loop() {
#if TRIG_FEATURE
  serviceTrigger();
#endif
#if EVENT_CHANNEL_ENABLED
  serviceEventChannel();
#endif
  while (Serial.available()) {
    char c = Serial.read();
    if (c == '\n' || c == '\r') {
      if (cmdPos > 0) {
        cmdBuffer[cmdPos] = '\0';
        processCommand(cmdBuffer);
        cmdPos = 0;
      }
    } else if (cmdPos < (int)(sizeof(cmdBuffer) - 1)) {
      cmdBuffer[cmdPos++] = c;
    }
  }

  // A train segment is due when the TIMER says so; frame and marker segments
  // remain millis()-scheduled, since their symbols are whole milliseconds and
  // their accuracy is not what the analysis leans on. Consuming edgeFired
  // here keeps the two paths from racing.
  bool timerDue = false;
  if (edgeFired) { uint8_t sr = SREG; cli(); edgeFired = false; SREG = sr; timerDue = true; }
  if (running && (timerDue || millis() >= nextToggleTime)) {
    if (mode == MODE_MARK) {
      // Marker pulse just ended: hold LOW for the configured pause. The run
      // clock is already running from the marker's leading edge, so timecode
      // stays referenced to the trigger instant, not to the end of the pause.
      mode = MODE_MARKPAUSE;
      setOutput(LOW);
      nextToggleTime = millis() + leadinPauseMs;
      scheduleEdgeUs((uint32_t)leadinPauseMs * 1000UL);
    } else if (mode == MODE_MARKPAUSE) {
      // Pause over: begin the pseudo-random train.
      mode = MODE_PR;
      setOutput(HIGH);
      schedulePrSegment();
    } else if (mode == MODE_FRAME) {
      // advance through the frame's 109 alternating segments
      frameSeg++;
      if (frameSeg > 108) {
        // frame done (ended on a pulse) — drop LOW and resume pseudo-random
        mode = MODE_PR;
        setOutput(LOW);
        schedulePrSegment();
      } else {
        setOutput(frameSeg % 2 == 0 ? HIGH : LOW);
        nextToggleTime = millis() + frameSegmentDuration(frameSeg);
      }
    } else if (mode == MODE_LEADIN) {
      // ON the tick: the first preamble pulse rises now
      startFrame();
      nextFrameDueMs += tcIntervalS * 1000UL;
    } else if (leadinPending) {
      // the clamped segment just ended at the lead-in start
      leadinPending = false;
      enterLeadIn();
    } else {
      bool next = !outputState;
      if (tcEnabled && next == HIGH &&
          (long)(nextFrameDueMs - TC_LEADIN_MS - millis()) < (long)TC_PULSE_MS) {
        // too close to the lead-in for a real pulse: stay LOW into it
        enterLeadIn();
      } else {
        setOutput(next);
        schedulePrSegment();
      }
    }
  }
}

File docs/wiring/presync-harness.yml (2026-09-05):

# PRE-Sync panel harness — WireViz source.
#
# Regenerate the diagram with:
#     tools/gen_wiring.sh
#
# Pin numbers are the Pro Micro variant (16 sync outputs, pins 2 and 3
# reserved for the trigger path). Only the 8 panel-wired outputs appear
# here; the remaining pins are unwired on this build.

connectors:
  MCU:
    type: Pro Micro ATmega32U4
    subtype: male header
    notes: >-
      Pro Micro. Outputs are two contiguous 4-way runs on the right header:
      A3-A0 (PORTF) and 15/14/16/10 (PORTB). A3-A0 are JTAG pins; the firmware
      clears JTD in MCUCR to use them as GPIO.
    pinlabels:
      - GND
      - A3 (21)
      - A2 (20)
      - A1 (19)
      - A0 (18)
      - D15
      - D14
      - D16
      - D10
      - D9 (spare)
      - D2 TRIG IN
      - D3 MODE SW
      - VCC

  OUT1:  {type: BNC, subtype: bulkhead, pinlabels: [centre, shield]}
  OUT2:  {type: BNC, subtype: bulkhead, pinlabels: [centre, shield]}
  OUT3:  {type: BNC, subtype: bulkhead, pinlabels: [centre, shield]}
  OUT4:  {type: BNC, subtype: bulkhead, pinlabels: [centre, shield]}
  OUT5:  {type: BNC, subtype: bulkhead, pinlabels: [centre, shield]}
  OUT6:  {type: BNC, subtype: bulkhead, pinlabels: [centre, shield]}
  OUT7:  {type: BNC, subtype: bulkhead, pinlabels: [centre, shield]}
  OUT8:
    type: BNC
    subtype: bulkhead
    pinlabels: [centre, shield]
    notes: >-
      EVENT when the event channel is enabled, otherwise an eighth sync
      output. The panel is eight BNCs plus TRIG IN either way -- enabling
      events converts this position rather than adding a connector. Carries a
      marker per trigger; the mark's leading edge is the event. Feed an LED
      converter or the 1-to-4 fan-out pod from here.

  TRIG:
    type: BNC
    subtype: bulkhead
    pinlabels: [centre, shield]
    notes: 1k series resistor in line. Input is INPUT_PULLUP.

  MODE:
    type: SPDT toggle
    subtype: MTS-102
    pinlabels: [FREE (open), common, TRIG (to GND)]
    notes: >-
      FREE RUN throw is the OPEN one. An unwired or failed-open switch then
      reads FREE RUN and the box emits, rather than sitting silent waiting
      for a trigger that never arrives.

  PWR:
    type: DC barrel
    subtype: 5.5x2.1 panel
    pinlabels: [+V, GND]

  GNDLUG:
    type: Ground screw
    subtype: 10-32
    pinlabels: [chassis]
    notes: Single ground point. Copper foil interior lining contacts here.

cables:
  W_OUT:
    wirecount: 8
    gauge: 24 AWG
    colors: [RD, OG, YE, GN, BU, VT, GY, WH]
    notes: >-
      Each conductor passes through its own series resistor at the BNC.
      All eight carry the same sync train, driven by two port writes so the
      channel-to-channel skew is ~0.13 us. The event channel is separate
      (pin 9) and is NOT part of this cable.

  W_GND:
    wirecount: 8
    gauge: 24 AWG
    colors: [BK, BK, BK, BK, BK, BK, BK, BK]
    notes: BNC shields to the common ground rail.

  W_TRIG:
    wirecount: 2
    gauge: 24 AWG
    colors: [BN, BK]

  W_MODE:
    wirecount: 2
    gauge: 24 AWG
    colors: [VT, BK]

  W_PWR:
    wirecount: 2
    gauge: 22 AWG
    colors: [RD, BK]

  W_CHASSIS:
    wirecount: 1
    gauge: 22 AWG
    colors: [GNYE]
    notes: Single chassis bond. The foil lining contacts the screw threads.

connections:
  # Eight sync outputs: one driver pin and one wire each.
  -
    - MCU: [2]
    - W_OUT: [1]
    - OUT1: [1]
  -
    - MCU: [3]
    - W_OUT: [2]
    - OUT2: [1]
  -
    - MCU: [4]
    - W_OUT: [3]
    - OUT3: [1]
  -
    - MCU: [5]
    - W_OUT: [4]
    - OUT4: [1]
  -
    - MCU: [6]
    - W_OUT: [5]
    - OUT5: [1]
  -
    - MCU: [7]
    - W_OUT: [6]
    - OUT6: [1]
  -
    - MCU: [8]
    - W_OUT: [7]
    - OUT7: [1]
  -
    - MCU: [9]
    - W_OUT: [8]
    - OUT8: [1]

  # BNC shields back to the common ground rail.
  -
    - OUT1: [2]
    - W_GND: [1]
    - MCU: [1]
  -
    - OUT2: [2]
    - W_GND: [2]
    - MCU: [1]
  -
    - OUT3: [2]
    - W_GND: [3]
    - MCU: [1]
  -
    - OUT4: [2]
    - W_GND: [4]
    - MCU: [1]
  -
    - OUT5: [2]
    - W_GND: [5]
    - MCU: [1]
  -
    - OUT6: [2]
    - W_GND: [6]
    - MCU: [1]
  -
    - OUT7: [2]
    - W_GND: [7]
    - MCU: [1]
  -
    - OUT8: [2]
    - W_GND: [8]
    - MCU: [1]

  # Trigger input (1k series resistor in line at the jack).
  -
    - TRIG: [1]
    - W_TRIG: [1]
    - MCU: [11]
  -
    - TRIG: [2]
    - W_TRIG: [2]
    - MCU: [1]

  # Mode switch: common to the pin, TRIG throw to ground.
  -
    - MODE: [2]
    - W_MODE: [1]
    - MCU: [12]
  -
    - MODE: [3]
    - W_MODE: [2]
    - MCU: [1]

  # Power.
  -
    - PWR: [1]
    - W_PWR: [1]
    - MCU: [13]
  -
    - PWR: [2]
    - W_PWR: [2]
    - MCU: [1]

  # Chassis bond: one point only, to avoid a ground loop.
  -
    - GNDLUG: [1]
    - W_CHASSIS: [1]
    - MCU: [1]

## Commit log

2026-02-12 Pseudo-random square wave sync pulse generator for Arduino Leonardo
    - Outputs randomized high/low durations on pins 2-5 for BNC sync cables
    - Configurable min/max timing ranges via Serial commands
    - Fixed PRNG seed (xorshift32) for reproducible patterns across runs
    - Sharp autocorrelation peak enables cross-correlation temporal alignment
    - Runtime commands: high/low ranges, seed, start/stop/restart
    [sync_pulse_generator.ino]
2026-02-12 Add config.h and EEPROM persistence
    - config.h: compile-time defaults for timing ranges, pins, seed
    - EEPROM save/load: settings survive power cycles after 'save' command
    - New serial commands: save, reset
    - Documents voltage (5V HIGH / 0V LOW, hardware fixed)
    [config.h, sync_pulse_generator.ino]
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2026-06-17 chore: replace org credit with author name in file header
    [sync_pulse_generator.ino]
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2026-08-28 fix(utils): channel search no longer collides with the device prefix
    Vicon labels analog channels 'Voltage.5-TA'. Searching the whole label for a
    short muscle abbreviation hit the prefix instead: 'TA' matched the 'ta' in
    every 'Voltage.', so find_channel silently returned all 16 channels and
    plot_sync_check drew the sync channel as a muscle trace.
    Now matches the label without its device prefix first, falling back to the
    full label only when that finds nothing — so 'TA' resolves to one channel
    while 'Voltage' still matches the whole device. Fixed in all three languages;
    R gained find_channel, which it did not have.
    Adds utils/python/test_edge_sync.py covering this and the other failure m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
2026-08-28 feat(utils): align.py — template-locked alignment of heterogeneous recordings
    Aligns any number of recordings onto one timeline, whatever form their sync
    evidence takes: a continuous analog copy of the square wave, rising-edge
    timestamps only, falling-edge timestamps only, or both. Sample rates may
    differ, start times may differ, and recordings need not overlap.
    The approach is not to align recordings to each other but to lock each one
    INDEPENDENTLY to the code-generated template, since the generator's output is
    fully determined by (seed, config). That makes alignment transitive — no
    reference device, no pairwise matrix, no accumulated error — and it is what
    lets an edge-only source a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
2026-08-28 feat(utils): align.py uses the binary timecode frames, not just the gaps
    The aligner previously ignored the timecode frames entirely and located every
    recording by pattern-matching the pseudo-random gaps. That threw away the
    better evidence: a decoded frame states its elapsed second outright, is
    checksum verified, needs no search, and is the ONLY thing identifying WHICH
    run was recorded — a fixed seed makes every run's waveform identical apart
    from the frame payload.
    Frames are now the primary lock, with the fingerprint as fallback:
    - decode_source_frames() reads the frames a recording carries. The decoder
    needs a single-polarity stream, since frame pulses have constant width but
    an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
2026-08-28 feat(utils): sliding frame-centred window, so corrections blend across cuts
    Segments previously started AT a decoded frame, which left every boundary
    extrapolating in one direction — exactly where the estimate has least support
    — and made the correction step at a cut rather than carry across it.
    The window now slides so each point sits between anchors on both sides, with
    adjacent windows overlapping. Measured against a clock whose rate wanders
    0 -> 400 ppm over 200 s, per edge, versus ground truth:
    one global line median 5.21 ms max 15.89 ms
    segment starts at a frame median 0.68 ms max 3.40 ms
    sliding, frame-centred median 0.66 ms max 3.28 ms
    Wideni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
2026-08-28 fix(utils): anti-alias before decimating in stitch
    Stitching to a lower rate used plain interpolation, which is silent
    corruption rather than mere inaccuracy: a 230 Hz tone taken from 2000 Hz to
    100 Hz came through at FULL amplitude disguised as 30 Hz, indistinguishable
    from real signal. Measured across 70/130/230/430 Hz, every one survived
    naive interpolation at 0.95 amplitude.
    Now low-passes with a zero-phase Butterworth (cutoff 0.45 * target) before
    resampling, so the filter adds no lag — which matters in a module whose whole
    purpose is timing. After the fix those same tones come through at 0.02-0.06
    while content below the new Nyquist is untouched (0.92-0.96).
    'nearest' is deliberate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
2026-08-28 feat(utils,matlab): timecode-aware signal generator, exact against Python
    generate_sync_signal_tc.m reproduces the firmware's hybrid output as EDGE
    TIMES including the timecode frames, which is what alignment needs. The
    existing generate_sync_signal.m predates timecode and emits only the pure
    pseudo-random train at a fixed sample rate, so it cannot serve as a template.
    Verified edge-for-edge against utils/python/timecode.py over 60 s with
    timecode on: 846 edges each, zero edges present in one and not the other.
    Getting there took four corrections, each a real firmware behaviour:
    - the first LOW->HIGH toggle happens at t=0, before any PRNG draw;
    - a pseudo-random segment crossing the lead-i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
2026-08-28 test(utils,matlab): self-tests for the aligner, 7/7 passing
    Mirrors utils/python/test_align.py. Verified in MATLAB R2024b against the
    same cases as the Python suite, with matching results:
    clean offset +20.0002, run 137 read from the frames, 100% matched
    rising-only +19.9996, 100%
    falling-only +20.0002, 100%
    300 ppm drift +301 ppm recovered, 100%
    lost-count step 2 segments, +251.5 ms (true 250)
    end-to-end lag +28.000 across 1000/2000 Hz sources
    decimation tones above the new Nyquist suppressed to <0.15
    The generator test guards the foundation directly — first toggle at t=0, no
    zero-width pulses, frames landing on the tick — since every alig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
2026-09-02 feat(firmware): free-run-only build, and fail-into-running for the mode switch
    Two changes, both addressing the same failure: a box that emits nothing.
    MODE_SWITCH_PIN is an INPUT_PULLUP, so an unwired or disconnected switch
    floats HIGH. With MODE_FREE_IS_LOW=1 that read as TRIG RUN — outputs held LOW
    waiting for a trigger that never came — so a box with no switch fitted, or one
    whose wire came loose mid-session, sat silent with no indication anything was
    wrong. Silence is the worst failure this device has, because it is only
    discovered later, in analysis, when nothing aligns.
    Inverted to MODE_FREE_IS_LOW=0: an unwired pin now reads FREE RUN and the box
    emits. A switch that fails open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
    [config.h, sync_pulse_freerun.ino]
2026-09-02 feat(trigger-box): brace the top opening, hang the PCB from cross beams
    The bottom edge is closed by the lid and both ends by the face and lid screws,
    but the top opening had nothing holding its long edges apart — 168 mm of
    unsupported wall free to bow. Two additions fix that:
    - A continuous ledge (2.5 x 3 mm) around the inside of the top rim, turning the
    free edge into a flange. A flange resists bending far better than the same
    mass added as wall thickness. It stops short of the corner posts so the face
    plate still seats on the posts, not on the ledge.
    - Two cross beams (8 x 4 mm) spanning the short way, wall to wall, at the PCB
    post spacing. They close the load path between the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
    [trigger-box.scad]
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2026-09-02 feat(firmware): trigger behaviour and lead-in marker are runtime settings
    Everything a host application needs to configure is now settable over serial
    and persisted to EEPROM, so changing how the box behaves no longer means
    editing config.h and reflashing. A config tool needs only a serial port — no
    AVR toolchain on the user's machine, no flash cycle per change, and nothing
    that can leave a board half-programmed.
    TRIGGER MODE (trigmode start|toggle|gate)
    start a rising edge starts a run; later edges ignored — the previous
    behaviour, kept as the default
    toggle a rising edge starts a run, the next edge stops it — trial
    start/stop from one line
    gate output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
    [config.h, sync_pulse_generator.ino]
2026-09-02 feat(utils): diagnose.py — template-free alignment, per-chunk QC, PDF reports
    align.py locks recordings to a template regenerated from the firmware, which
    is the stronger method but needs the seed and timing config to match. It
    cannot help with a recording made on the simple bench firmware, on a box whose
    settings were never written down, or from a different generator entirely — and
    on exactly that data it failed both streams outright with "no window reached
    usable confidence".
    diagnose.py aligns two recordings to EACH OTHER from their interval patterns
    alone. No template, no seed, no configuration.
    Every guard in it exists because the naive version produced a confident WRONG
    answer on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
2026-09-02 feat(utils): truth.py — score any recording against the emitted waveform
    The signal is deterministic, so the waveform that was on the wire can be
    regenerated exactly and used as ground truth. A recording is then judged
    against what was EMITTED rather than against another recording — which
    matters because a pairwise comparison cannot say which of two recordings is
    at fault, and on the UVM data both were.
    Reports four faults separately, because they need different responses:
    OFFSET constant lag — correctable exactly
    DRIFT recorder clock rate — correctable, but a constant offset will not
    hold across a long trial without it
    JITTER what remains after both — irreduci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
2026-09-02 feat(utils): separate dropout damage from a recorder's real timing
    A dropout does not only remove its own transition — the ones on either side
    of a gap are the most likely to be mistimed. Including them charges the
    dropout's damage to the recorder's timing and hides which fault you actually
    have.
    score() now reports timing twice: over all captured transitions, and over
    only those more than guard_s from any loss. The gap between the two is the
    diagnosis.
    On the UVM wireless session the two streams separate cleanly:
    Kinarm jitter 2.44 -> 0.46 ms once dropout-adjacent transitions are
    excluded (max 28.36 -> 1.06). Its timing is as good as in the wired
    session (0.43 ms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
2026-09-02 feat(utils): classify() — separate jitter, gross errors, outages, isolated misses
    Lumping these together is why the same recording reported anywhere from
    0.5 ms to 2.6 ms of "jitter" depending on how it was sliced. Each is now
    counted on its own, and each points at a different fix.
    JITTER spread of the well-behaved transitions, reported in ms AND in
    PRE-Sync quanta. Since the generator can only emit multiples of
    5 ms, a recorder inside +/-0.5 quanta can never be assigned to
    the wrong tick — that is a meaningful acceptance criterion, where
    an arbitrary millisecond threshold is not.
    GROSS single transitions off by more than 3 qua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
2026-09-02 feat(utils): analyze.py — one call, full analysis, full report
    python analyze.py recording.xdf --pdf report.pdf
    Runs everything the toolkit can determine about recordings sharing the
    PRE-Sync signal, and keeps each quantity separate from the others. Lumping
    them is how the same recording came to report anywhere from 0.5 to 2.6 ms of
    "jitter" depending on how it was sliced.
    Reported per stream, each with a different cause and a different remedy:
    OFFSET constant lag — subtract it. If this is all that is wrong, the
    acquisition software's timestamps can be trusted.
    DRIFT ppm, with ms/min and ms/hour spelled out, because it ACCUMULATES
    and is invisibl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
2026-09-02 perf(utils): coarse-then-fine lock; fix reference choice with many streams
    Two problems that only appeared once more than two streams were analysed at
    once.
    SPEED. Locating a stream compared every probe window against every window of
    a six-hour template — 25.6 million comparisons, 8.7 s of Python loop per
    stream, so eight streams took 9.9 s and sixteen would have taken forty.
    Now: one probe window narrows the template to a neighbourhood (a matching
    8-interval run is already nearly unique in a pseudo-random sequence), and the
    full scoring runs only there, then re-anchors on the middle of the recording
    where a damaged start or end matters less. 8 streams in 3.5 s, with every
    reported figur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
2026-09-04 Move the stiffening ledge and cross beams to the top of the box
    They were built at the lid end. The lid is the BOTTOM of the deployed box
    (lid_part: "Lid (bottom when deployed)"), so the bracing sat on the bottom
    edge — the one the lid already ties together — and the PCB posts stood
    upward, holding the board above the beams instead of hanging it beneath.
    The face plate is the top, at z=0 in model coordinates, so the ledge and
    beams now build there. Posts run +z, which is downward on the deployed box,
    and the board hangs under the beams as intended: serviceable from either
    end, with the component side facing the removable lid.
    Also flipped the flared post root, which was tapering the wr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
    [trigger-box.scad]
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2026-09-04 Add generated electrical schematic
    Completes the documentation package. The harness diagram says which wire
    goes where physically; this says what the circuit is -- the per-channel
    series resistors, the two internal pullups, and the switch polarity -- with
    the reason for each carried as a note rather than left implicit.
    Generated from docs/wiring/presync-schematic.yml by tools/gen_schematic.py,
    for the same reason the other three are generated: a schematic nobody
    regenerates drifts from the device it describes.
    Deliberately not KiCad. The circuit is eight driver pins through series
    resistors plus two pulled-up inputs, and a full EDA project would add a
    binary file that does not diff, for a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
    [gen_schematic.py]
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2026-09-05 Size the gooseneck insert pockets to the actual part (McMaster 151030)
    The insert is INS 29/250-20/.312L: 0.290" OD (7.37 mm), 0.312" long
    (7.92 mm), 1/4"-20. The pocket was 7.6 mm diameter and 10 mm deep, which is
    wrong in the direction that matters -- a heat-set insert needs a hole SMALLER
    than its OD, because the plastic melts and flows into the knurling and that
    interference is the entire retention mechanism. At 7.6 mm a 7.37 mm insert
    drops in with slop, sets crooked, and spins under the first real torque,
    which on a gooseneck is every repositioning.
    hole 7.6 -> 7.07 mm (OD - 0.3, leaving 0.15 mm per side to melt)
    depth 10 -> 9.5 mm (insert 7.92 + room for displaced plastic)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
    [pods.scad]
2026-09-05 Fix the POD base plate: countersinks and keyhole were both on the wrong face
    base() is the bottom plate but called plate_screws(), which is the top-plate
    variant and flares the countersink UPWARD -- so the cones opened into the pod
    interior and four screw heads stood proud of the bottom face. The correct
    plate_screws_bottom() already existed and was already used elsewhere, so this
    was an oversight rather than a choice.
    The keyhole had the same problem as the box lid: a straight through-cut with
    nowhere for the mounting screw head to recess. Added a 15 mm counterbore
    2 mm into the 3 mm wall, swept along the slot so the head stays recessed
    through the full travel.
    Between them the pod was re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
    [BOM.csv, pods.scad]
2026-09-05 5mm LED head: taper to a 4.9 mm mouth, gooseneck barrel socket at the back
    The LED loads from the back and stops on a cone rather than a flat shoulder.
    A ledge has to be dimensioned to a tolerance the printer may not hold -- on
    this LED the lip is only ~0.3 mm wider than the body, which left roughly one
    layer line of bearing surface. A taper stops the LED wherever its diameter
    matches, self-centres it on the way in, and cannot fall through because the
    4.9 mm mouth is narrower than the measured 5.22 mm lip.
    z 0-12 gooseneck barrel socket, 12.95 mm, with a side grub screw
    z 12-15 lip bore, 5.72 mm
    z 15-18 taper, 5.72 -> 4.90 at the front face
    The back end takes the gooseneck's smoo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
    [pods.scad]
2026-09-05 5mm LED head: remove the grub screw, add a leg relief, keep it 18 mm
    Three fixes, all defects I introduced earlier in this session:
    REMOVED THE GRUB SCREW. I added an M3 cross-hole to clamp the gooseneck,
    having assumed a smooth press-fit barrel needed mechanical retention. It was
    never asked for and it puts a hole through the side of a lit part.
    ADDED A LEG RELIEF. The LED body bore ran the full depth at 5.72 mm against a
    5.22 mm body, leaving 0.25 mm per side. The legs run back from the LED's base
    and had nowhere to go, so there was no wire path from the LED cavity into the
    gooseneck socket. The bore now opens to 9 mm behind the seat.
    KEPT IT 18 MM. Sizing each region generously and sta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
    [pods.scad]
2026-09-05 Report firmware, protocol and hardware versions; fix the config pin list
    THREE VERSIONS, tracked separately because they change for different reasons.
    Collapsing them into one number is what makes old recordings undecodable --
    you can no longer tell whether a bump changed the signal or fixed a typo.
    FW_VERSION 1.1.0 this build; bump for any change
    PROTOCOL_VERSION 2 THE SIGNAL ON THE WIRE; bump only when a decoder
    written for the previous version would mis-read
    this one (frame layout, symbol widths, marker
    shape, PRNG or its draw order)
    HW_VARIANT leonardo the physical build; sets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
    [config.h, sync_pulse_generator.ino]
2026-09-05 Duration quantum 5 ms -> 1 ms; protocol 3; correct Pro Micro build
    The pseudo-random durations are now drawn on a 1 ms step instead of 5 ms.
    That is 451 distinct durations per draw instead of 91: four intervals span
    41 billion combinations rather than 68 million, so a short fingerprint probe
    is unique across days of signal and a dropout defeats the search far less
    often. 1 ms is also the firmware's native resolution -- the sim loop
    schedules on millis(), which cannot express anything finer.
    It does NOT change jitter measurement. Jitter is the spread of
    (recorded - true) and the true edge time is read off the template exactly,
    whatever the step. What it changes is the "quanta" figure and the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
    [config.h, sync_pulse_generator.ino]
2026-09-05 Timer-driven emission, 8 panel outputs, 250 us quantum (protocol 4)
    Edges are now placed by a Timer3 compare-match ISR instead of by polling
    millis() in the main loop, and the eight panel outputs are flipped with two
    port writes instead of eight digitalWrite() calls.
    WHY THE TIMER. Polling puts the edge wherever the loop happens to reach it:
    0 to 200+ us late, varying with serial traffic. Switching to micros() would
    not have fixed that -- it changes what can be EXPRESSED, not when the pin
    moves. A compare match fires in hardware, so the only delay is ISR entry:
    ~17 cycles at 62.5 ns = ~1.06 us, and CONSTANT, which makes it a fixed offset
    rather than jitter.
    WHY PORT WRITES. digitalWrite()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
    [config.h, sync_pulse_generator.ino]
2026-09-05 Base the protocol numbering on the git history, not on this session
    The protocol numbers were assigned from memory during the session, which
    missed a real boundary and invented one that never shipped. Reconstructed
    from the repository:
    1 64e548d..c9abef0 Feb-Jun 2026 pure pseudo-random, 5 ms steps
    2 63b72e9..25015f1 Aug-Sep 2026 adds timecode frames
    3 6844f39..f4d79c9 Sep 2026 adds the event channel
    4 df48b76 onward Sep 2026 250 us quantum, timer-driven, 8 outputs
    Two corrections fall out of that.
    TIMECODE WAS A PROTOCOL BOUNDARY AND HAD NO NUMBER. 63b72e9 started
    interrupting the train every 10 s with a 52-bit frame; a decoder written
    before it reads tho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
    [config.h]
2026-09-05 Two 4-way headers for the outputs; free the A-pins from JTAG; add pintest
    PIN LAYOUT. The eight outputs now sit as two contiguous runs of four on the
    Pro Micro's right-hand header -- 21,20,19,18 then 15,14,16,10, rows 4 to 11 --
    so a pair of 4-way ribbon connectors reaches them with no skipped positions
    and no crossing wires.
    Header contiguity and the two-port-write layout normally fight each other:
    most contiguous runs cross three or four ports. On this board they coincide,
    because A3..A0 are all PORTF and 15/14/16/10 are all PORTB.
    JTAG. PF4-PF7 (A3..A0) are the JTAG pins TCK/TMS/TDO/TDI, and with the
    factory JTAGEN fuse the JTAG interface owns them: writing PORTF does nothing
    and four o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
    [config.h, sync_pulse_generator.ino]
2026-09-05 Regenerate the docs for the new pin layout
    INTERFACE.md now derives the output list from PANEL_PINS rather than the
    OUTPUT_PINS array. The old array is the full set of GPIO the firmware once
    swept; the panel set is what the ISR actually port-writes. Reporting the
    former listed 17 and 15 channels that do not exist as panel outputs.
    It now shows the two 4-way headers per board, and carries the JTAG warning:
    A3-A0 are PF4-PF7, and without the JTD write four channels never toggle
    despite a clean compile and a correct-looking config.
    The harness diagram and schematic follow the same pin set, and the event
    channel is now drawn as its own connector rather than being labelled onto
    OUT8, which it s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
    [presync-harness.bom.tsv]
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2026-09-05 Fix an interrupt storm from OCR3A = 0, and park the timer on stop
    Two bugs, both showing on the panel LED.
    INTERRUPT STORM. armTimer() could set OCR3A to 0. In CTC mode a compare value
    of 0 with TCNT3 at 0 matches on essentially every tick, so the ISR re-entered
    at ~2 MHz: the main loop never ran, USB stopped being serviced and the board
    dropped off the bus while the pins kept toggling.
    That is one bug behind three symptoms -- a box that blinks but cannot be
    talked to, runs that stop at random, and a dim flicker in TRIG RUN instead of
    a clean off. It was intermittent because a zero chunk only arises when a
    duration divides exactly into TIMER_MAX_TICKS, which depends on the draw.
    Recovery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
    [sync_pulse_generator.ino]
2026-09-05 Move BNC 2 from pin 20 (A2) to pin 9
    Hardware fault on the A2 connection: the same wire and BNC work on any other
    channel, and the port readback shows PF5 setting and clearing correctly, so
    the silicon and the pad are fine and the break is at that pin's joint.
    Rather than chase the solder, BNC 2 moves to pin 9. PB5 is on the same port
    as the other PORTB outputs and sits directly above pin 10 on the header, so
    the layout keeps its two port writes and the right-side run stays contiguous
    -- just no longer in numeric order.
    PORTF 0xF0 -> 0xD0 (A2 dropped)
    PORTB 0x2E with events on, 0x6E with them off
    A2 is now unused.
    NOTE ON pintest: PINF/PINB read the state of the PAD, which the po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
    [config.h]
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
